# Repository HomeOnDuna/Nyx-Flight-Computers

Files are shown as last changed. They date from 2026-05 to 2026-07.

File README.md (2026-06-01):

# Nyx-Flight-Computer
Contains all details of the Nyx family of flight computers developed by Timothy Paige for UNSW rocketry

How to use:
 - Make a local clone of the entire repositry
 - Open the project you want from the file it is in
 - Enjoy!

To add parts to the library:
 - All parts go in the UNSW Rocketry parts folder (single parrts library)
 - Open a project and add the symbol into the UNSW Rocketry Library (symbol library, via import)
 - Put the footprint in the footprints.pretty folder of the parts folder
 - Put the 3D model in the 3D models folder
 - In the project, edit the symbol you have imported and assign the default footprint to the footprints.pretty folder footprint (.kicad_mod)
 - Edit the footprint you just added to add in the 3D model

How to reference filepaths:
**Do not use the default filepaths KiCAD generates. These will only work on your device!**
 - Remove the filepath up to Nyx-Flight-Computers (leave the \ after this)
 - Insert .. before this, which then re-references to a relative filepath (permitting multi-device use).

Current capabilites:
 - Literally nothing

Future capabilities targets:
 - Flight data recording from multiple sources to memory (SD cards)
 - Detection of phase of flight (not vehicle direction, speed etc., only are we 1) accelerating, and 2) going up or going down) and subsequent actions or data recording changes
 - Flight data high-speed capability to RAM during boost phase
 - Telemetry of currently relevant data
 - Pyro / chute deploy devices (linear actuator or other form)
 - Basic marking out of failed / erroring sensors in data recording

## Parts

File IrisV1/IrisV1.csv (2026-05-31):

Reference | Qty | Value | DNP | Exclude from BOM | Exclude from Board | Footprint | Datasheet
A3 | 1 | LPS22DFTR |  |  |  | Baro 1:XDCR_LPS22DFTR
C2,C3,C4,C10 | 4 | 10uF |  |  |  | Capacitor_SMD:C_0603_1608Metric
C8,C21,C22,C26,C27,C32,C34,C35,C36 | 9 | 100nF |  |  |  | Capacitor_SMD:C_0603_1608Metric
C12,C13,C14 | 3 | 22uF |  |  |  | Capacitor_SMD:C_0603_1608Metric
C15,C24 | 2 | 47uF |  |  |  | Capacitor_SMD:C_0603_1608Metric
C20 | 1 | 1uF |  |  |  | Capacitor_SMD:C_0603_1608Metric
D1,D2,D3,D4 | 4 | LED |  |  |  | LED_SMD:LED_0603_1608Metric
D5 | 1 | PRTR5V0U2X |  |  |  | Package_TO_SOT_SMD:SOT-143 | https://assets.nexperia.com/documents/data-sheet/PRTR5V0U2X.pdf
J1,J7 | 2 | Conn_02x02_Odd_Even |  |  |  | Connector_PinHeader_2.54mm:PinHeader_2x02_P2.54mm_Vertical
J3 | 1 | USB4110GFA |  |  |  | USB:GCT_USB4110GFA
J4 | 1 | Conn_01x04 |  |  |  | Connector_PinHeader_2.54mm:PinHeader_1x04_P2.54mm_Vertical
J5,J6 | 2 | MSD-10-C |  |  |  | microSd card locking:CUI_MSD-10-C
J13,J14,J16,J21,J22 | 5 | TB002-500-02BE |  |  |  | screw terminal:CUI_TB002-500-02BE
L1 | 1 | 1.5uH |  |  |  | inductor:1277AS-H-1R0M=P2_MUR-M
LS1 | 1 | CMI-1295-03TH |  |  |  | low volt buzzer:SPKR_CMI-1295-03TH
Q1 | 1 | SI4909DY-T1-GE3 |  |  |  | pyro 1:SOIC_09DY-T1-GE3_VIS | https://www.vishay.com/doc?67077
Q2 | 1 | MBT3904DW1T1G |  |  |  | npn 1:SOT-363&slash_SC-88&slash_SC70-6&slash_CASE419B_OSI | MBT3904DW1T1G
R1,R2,R16,R24,R27,R28 | 6 | 1k |  |  |  | Resistor_SMD:R_0603_1608Metric
R3,R4,R5,R6 | 4 | 1.3k |  |  |  | Resistor_SMD:R_0603_1608Metric
R7,R8,R10,R13,R19,R22,R25,R26,R31,R58 | 10 | 10k |  |  |  | Resistor_SMD:R_0603_1608Metric
R9 | 1 | 100k |  |  |  | Resistor_SMD:R_0603_1608Metric
R11 | 1 | 470k |  |  |  | Resistor_SMD:R_0603_1608Metric
R12 | 1 | 150k |  |  |  | Resistor_SMD:R_0603_1608Metric
R15,R23 | 2 | 9k |  |  |  | Resistor_SMD:R_0603_1608Metric
R17,R18 | 2 | 5.1k |  |  |  | Resistor_SMD:R_0603_1608Metric
R29,R32 | 2 | 39k |  |  |  | Resistor_SMD:R_0603_1608Metric
R30,R57 | 2 | 56k |  |  |  | Resistor_SMD:R_0603_1608Metric
R45,R46 | 2 | 3.3k |  |  |  | Resistor_SMD:R_0603_1608Metric
TP1,TP2,TP3,TP4,TP5,TP6,TP7,TP8,TP9,TP10 | 10 | TestPoint |  |  |  | TestPoint:TestPoint_Pad_D1.5mm
U1 | 1 | LSM6DSV80XTR |  |  |  | Acc 1:QFN_LSM6DSV80XTR_STM | https://www.st.com/resource/en/datasheet/lsm6dsv80x.pdf
U2 | 1 | ESDS302DBVR |  |  |  | esd:DBV0005A_L | https://www.ti.com/lit/gpn/esds302
U3 | 1 | ESP32-S3-WROOM-1U-N4 |  |  |  | ESP32-S3:XCVR_ESP32-S3-WROOM-1U-N4
U18 | 1 | MS561101BA03-50 |  |  |  | ms5611:SON8_MS5611_TEC | https://www.te.com/commerce/DocumentDelivery/DDEController?Action=srchrtrv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
U20 | 1 | BMI323 |  |  |  | BMI323:BMI323_BOS | BMI323
U22 | 1 | TPS63070RNMR |  |  |  | TPS63070:RNM0015A | https://www.ti.com/lit/gpn/tps63070

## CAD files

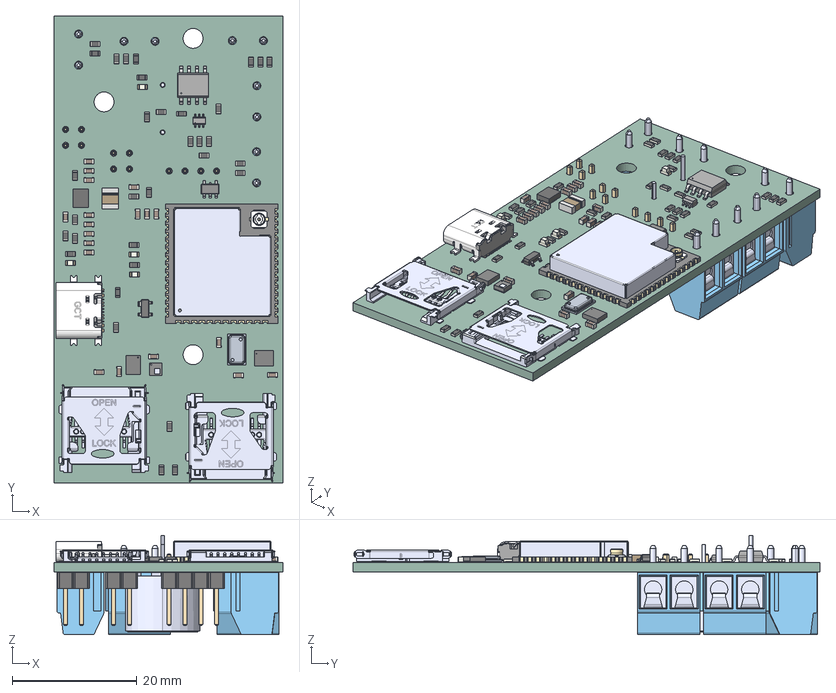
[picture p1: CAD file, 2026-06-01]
IrisV1/.step
36.7 x 75.0 x 16.0 mm
C_0603_1608Metric x 19
R_0603_1608Metric x 33
c-ms561101ba03-50-1-3d
SOT-363SC-88SC70-6CASE419B_OSI
SOT-143
LPS22DFTR
USB4110-GF-A_revB(1) MF
LED_0603_1608Metric x 4
MSD-10-C x 2
BMI323_BOS
ESP32-S3-WROOM-1U-N4
BODY-SOT
LEAD-SOT x 5
LEAD-DUMMY
QFN_LSM6DSV80XTR_STM
FRAME-RNM0015A
BODY-QFN
PIN1-ID
1277AS-H-1R0MP2_MUR
SOIC_09DY-T1-GE3_VIS
CMI-1295-03TH
PinHeader_2x02_P2.54mm_Vertical x 2
TB002-500-02P_Blue - S x 5
PinHeader_1x04_P2.54mm_Vertical
IrisV1_PCB

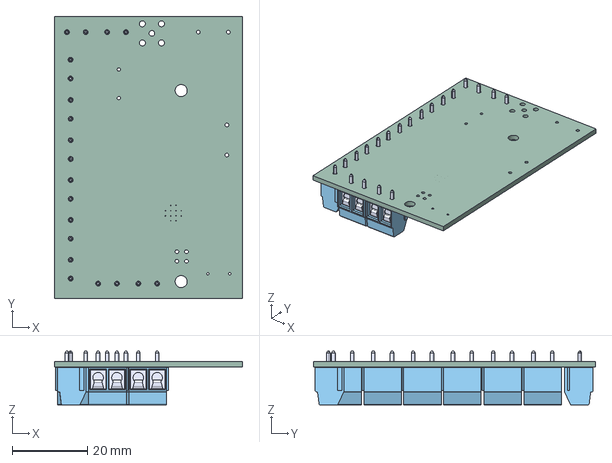
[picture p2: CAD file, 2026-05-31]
OneiroiV1/.step
50.0 x 75.0 x 14.4 mm
TB002-500-02P_Blue - S x 10
OneroiV1_PCB

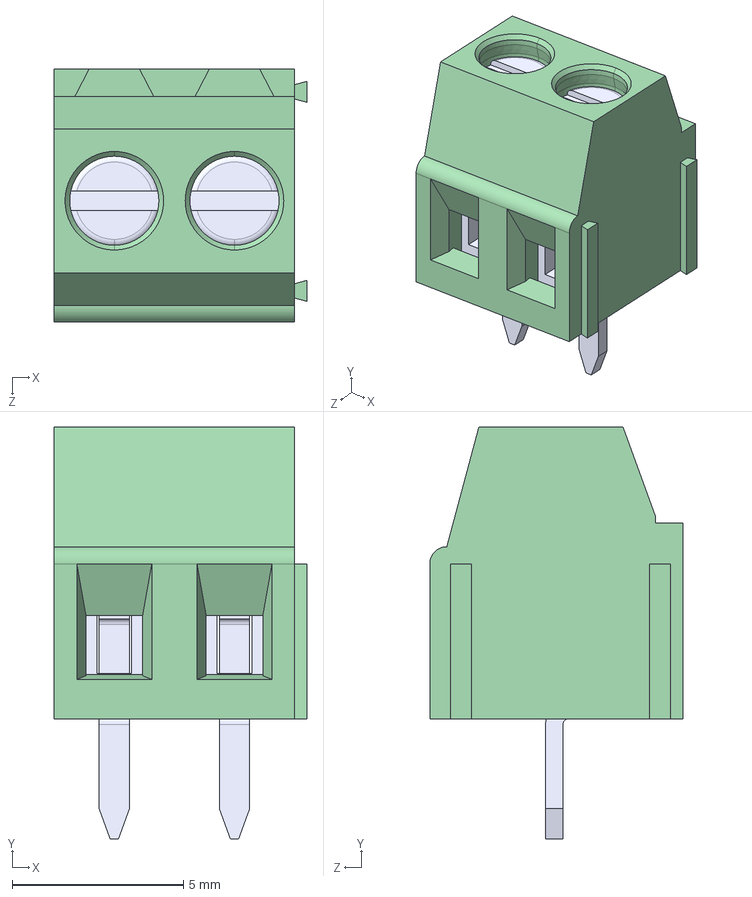
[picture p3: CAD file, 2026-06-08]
UNSW Rocketry Parts/3D models/EBWA-02-A.step
7.37 x 12.0 x 7.39 mm

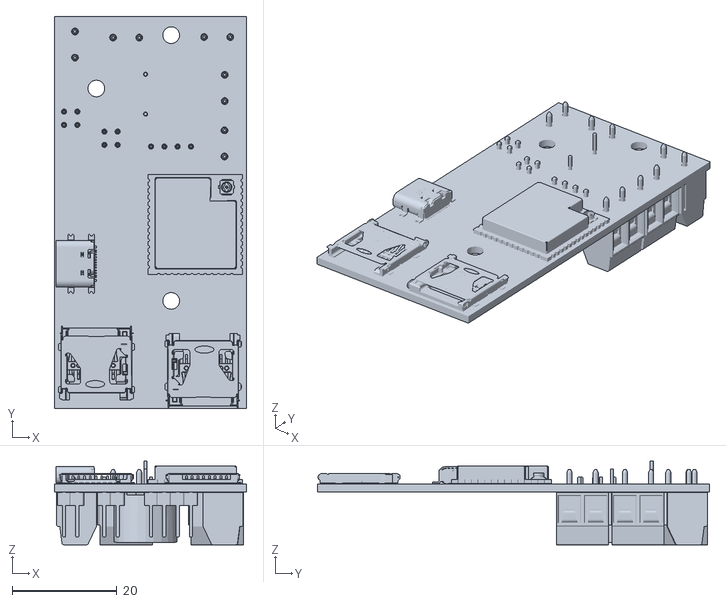
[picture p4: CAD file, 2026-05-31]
IrisV1/.stl
36.7 x 75.0 x 16.0

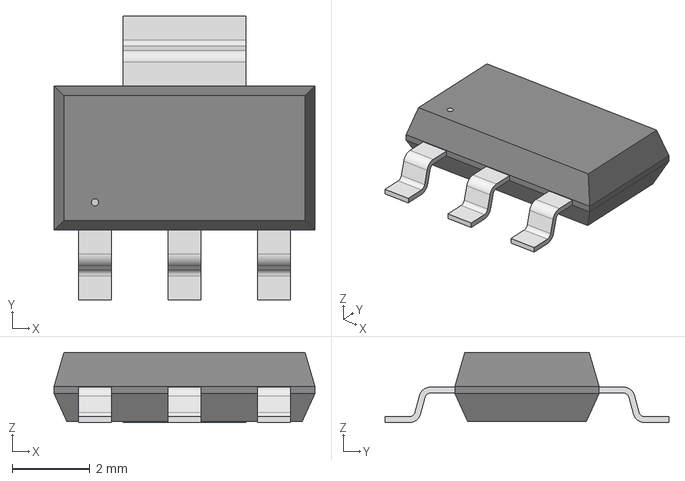
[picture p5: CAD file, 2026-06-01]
UNSW Rocketry Parts/3D models/SOT223_STM.step
6.71 x 7.29 x 1.81 mm

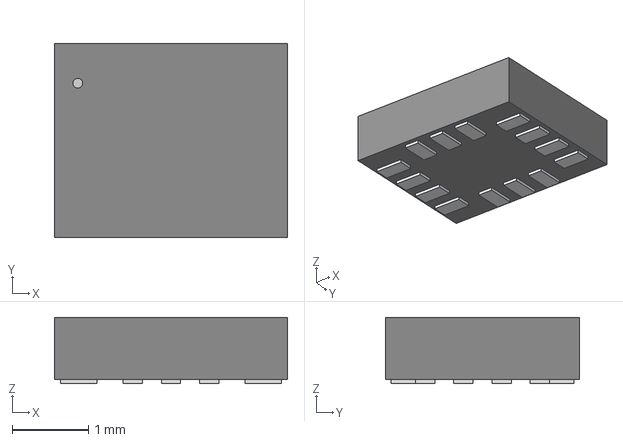
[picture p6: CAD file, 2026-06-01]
UNSW Rocketry Parts/3D models/BMI270_BOS.step
3.05 x 2.54 x 0.866 mm

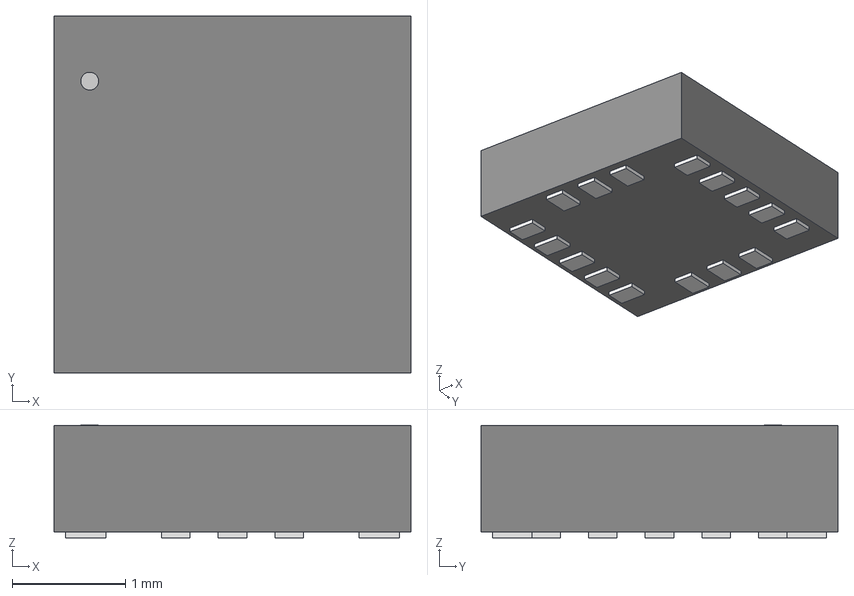
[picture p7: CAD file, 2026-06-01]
UNSW Rocketry Parts/3D models/QFN_31DLTR_STM.step
3.15 x 3.15 x 0.993 mm

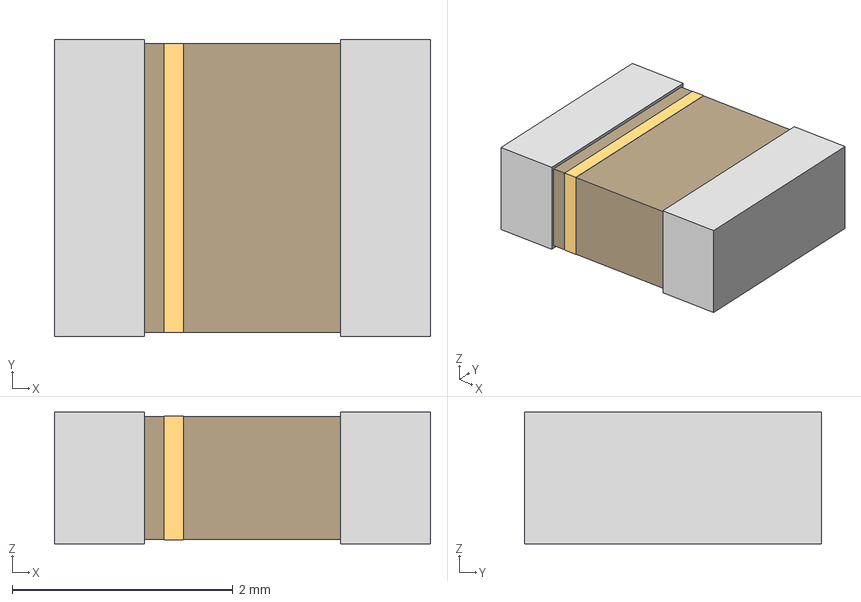
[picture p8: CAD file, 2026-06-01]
UNSW Rocketry Parts/3D models/1277AS-H-1R0MP2_MUR.step
3.40 x 2.69 x 1.19 mm

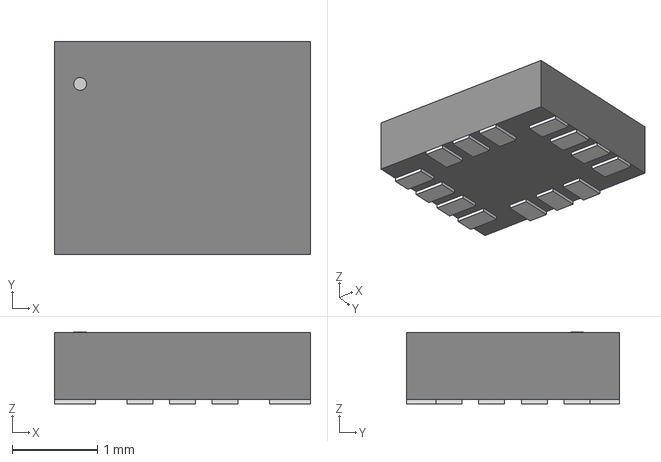
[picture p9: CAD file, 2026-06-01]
UNSW Rocketry Parts/3D models/QFN_LSM6DSV80XTR_STM.step
3.00 x 2.49 x 0.841 mm

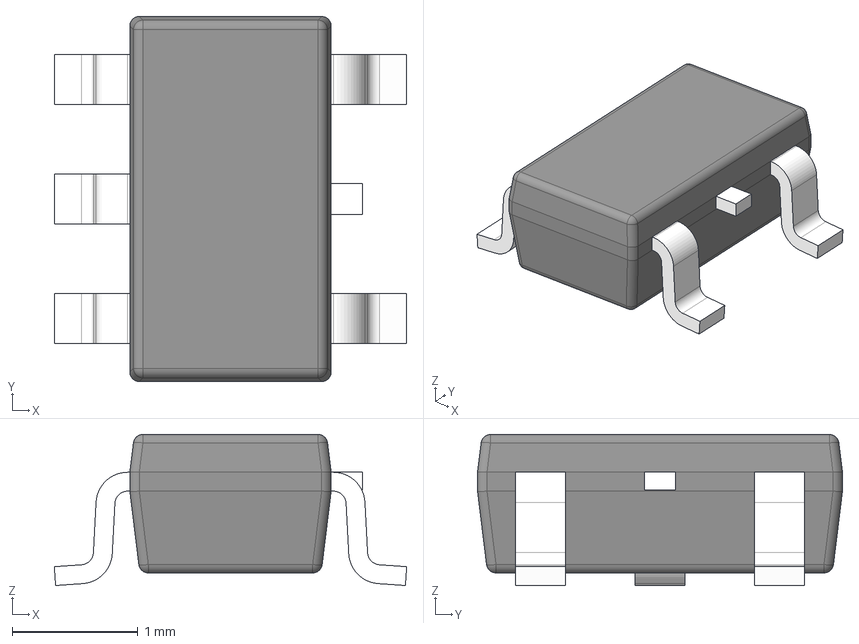
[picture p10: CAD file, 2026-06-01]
UNSW Rocketry Parts/3D models/DBV0005A.stp
2.80 x 2.90 x 1.20 mm
BODY-SOT
LEAD-SOT x 5
LEAD-DUMMY

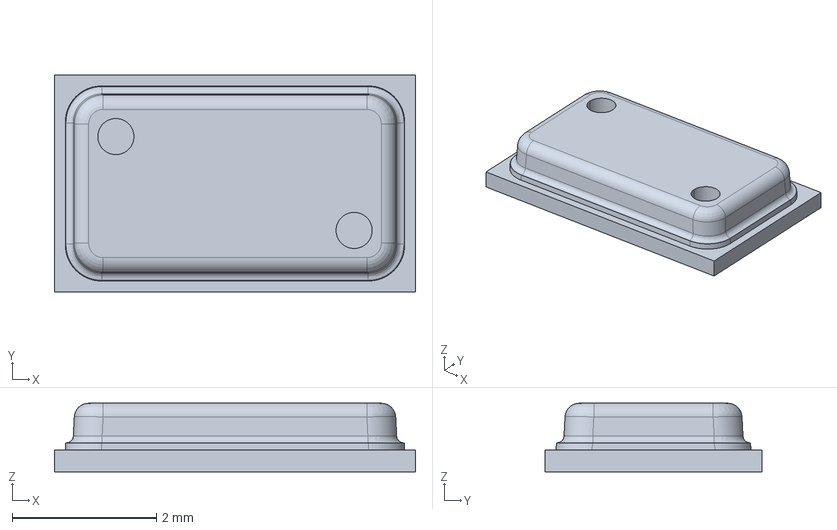
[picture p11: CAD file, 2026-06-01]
UNSW Rocketry Parts/3D models/c-ms561101ba03-50-1-3d.stp
5.00 x 3.00 x 0.95 mm

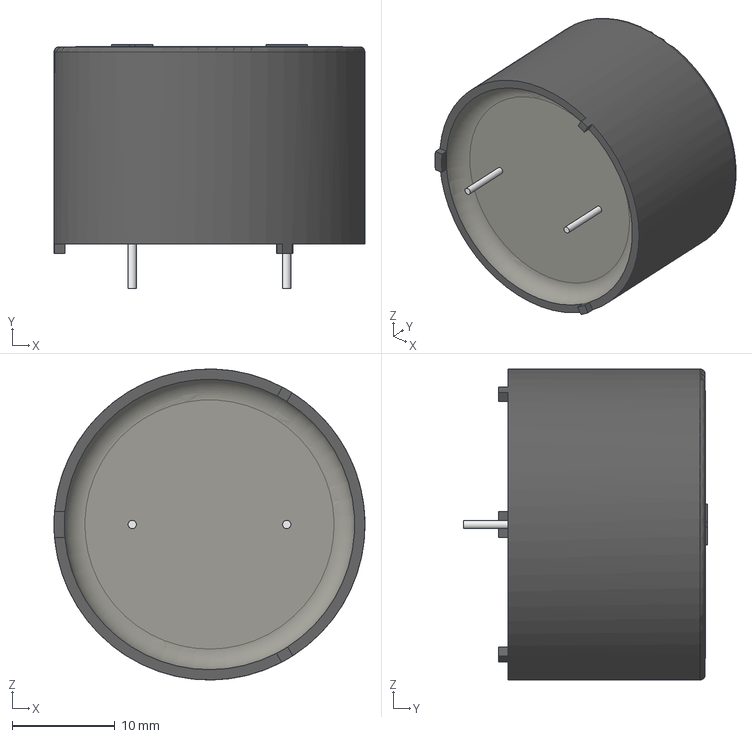
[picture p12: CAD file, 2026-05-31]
UNSW Rocketry Parts/3D models/AI-3035-TT-12V-R.step
30.2 x 23.6 x 30.2 mm

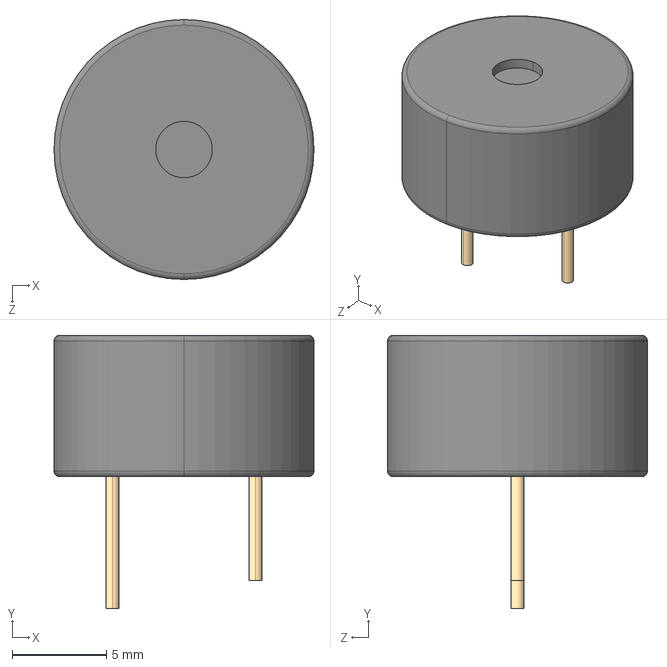
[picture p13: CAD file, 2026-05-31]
UNSW Rocketry Parts/3D models/CPI-1375-80T.step
13.8 x 14.5 x 13.8 mm

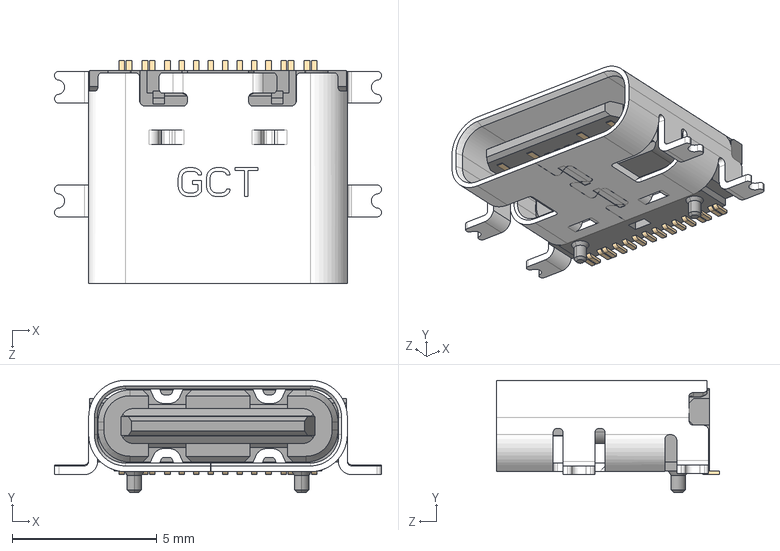
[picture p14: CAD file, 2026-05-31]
UNSW Rocketry Parts/3D models/USB4110GFA.step
11.3 x 3.89 x 7.70 mm

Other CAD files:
UNSW Rocketry Parts/3D models/TB002-500-02BE.step
UNSW Rocketry Parts/3D models/DRL0008A.stp
UNSW Rocketry Parts/3D models/IC_DMP3028LSD-13_DIO.step
UNSW Rocketry Parts/3D models/MSD-10-C.step
UNSW Rocketry Parts/3D models/3-1478978-1.step
UNSW Rocketry Parts/3D models/BMI323_BOS.step
UNSW Rocketry Parts/3D models/CMI-1295-03TH.step
UNSW Rocketry Parts/3D models/CONSMA001-SMD-G-T.step
UNSW Rocketry Parts/3D models/ESP32-S3-WROOM-1U-N4.step
UNSW Rocketry Parts/3D models/LPS22DFTR.step
UNSW Rocketry Parts/3D models/MAX-M10S-00B.step
UNSW Rocketry Parts/3D models/MSD-4-A.step
UNSW Rocketry Parts/3D models/RNM0015A.stp
UNSW Rocketry Parts/3D models/RUX0012A.stp
UNSW Rocketry Parts/3D models/SOIC_09DY-T1-GE3_VIS.step
UNSW Rocketry Parts/3D models/SOT-363SC-88SC70-6CASE419B_OSI.step
UNSW Rocketry Parts/3D models/SOT-363_DIO.step
UNSW Rocketry Parts/3D models/UFV_z90.stp

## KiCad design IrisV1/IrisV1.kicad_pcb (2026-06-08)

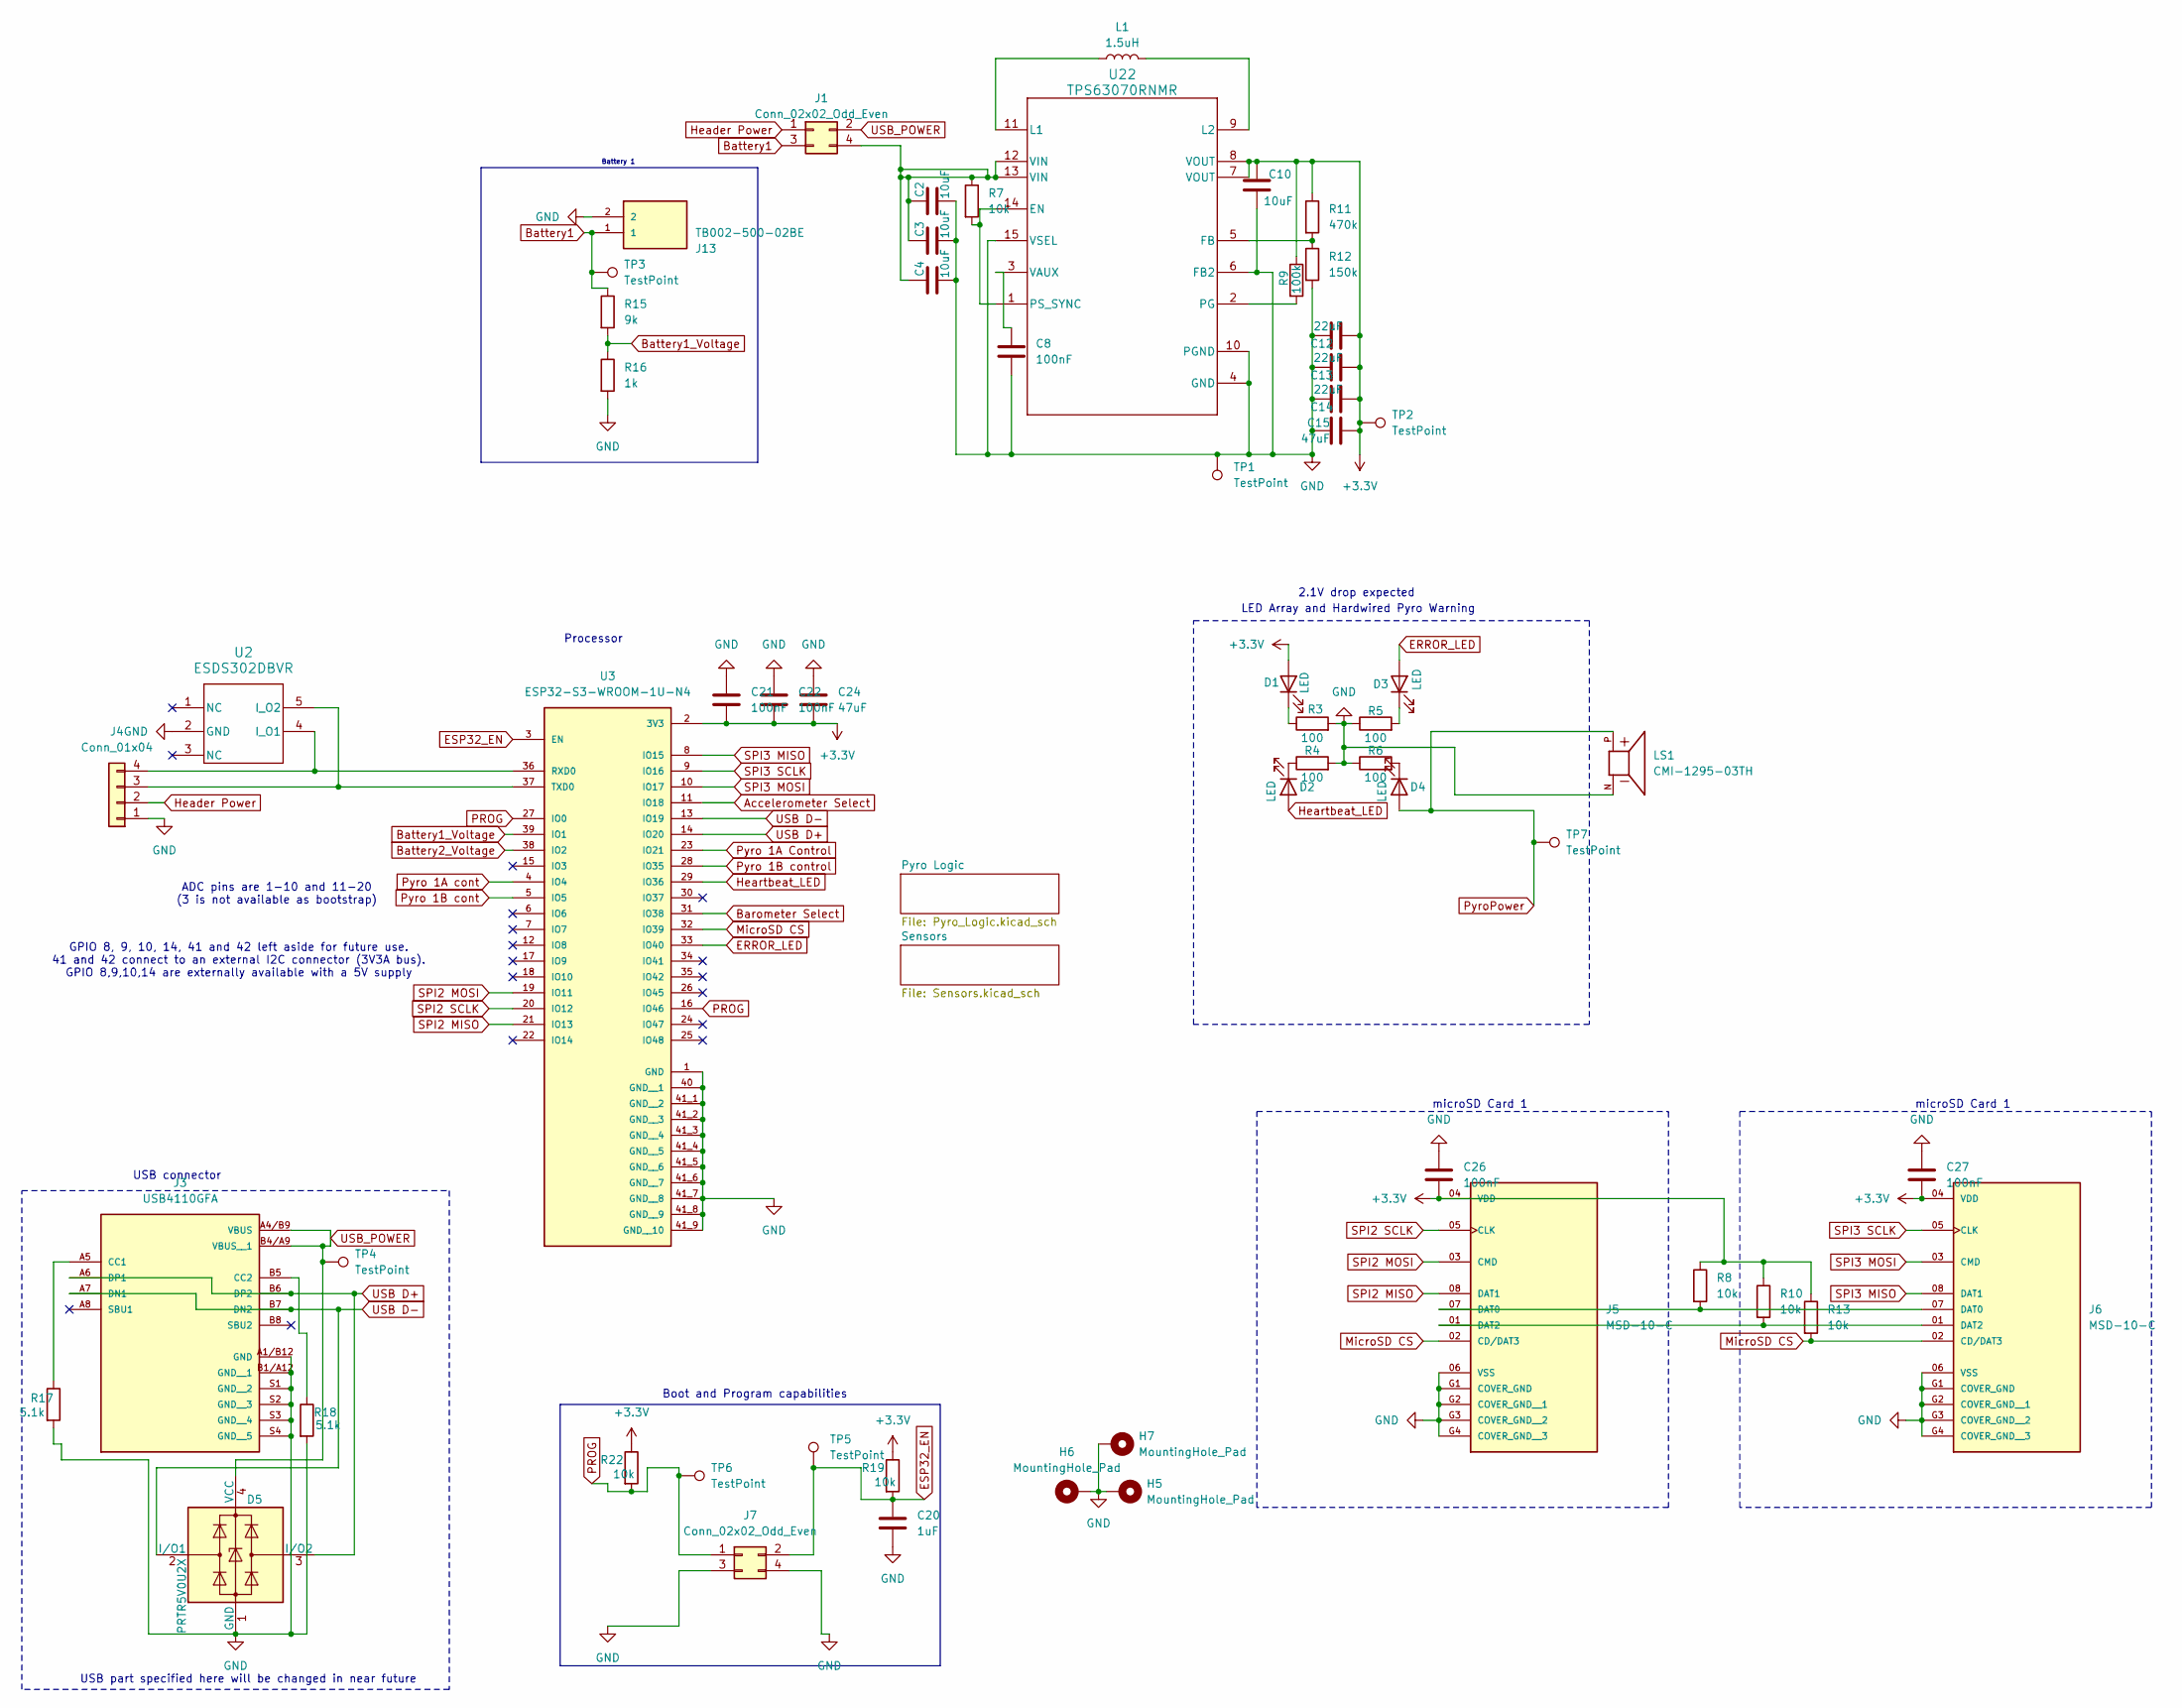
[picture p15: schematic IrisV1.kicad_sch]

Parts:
C2, C3, C4, C10: 10uF; C_0603_1608Metric
C8, C21, C22, C26, C27: 100nF; C_0603_1608Metric
C12, C13, C14: 22uF; C_0603_1608Metric
C15, C24: 47uF; C_0603_1608Metric
C20: 1uF; C_0603_1608Metric
D1, D2, D3, D4: LED; LED_0603_1608Metric
D5: PRTR5V0U2X; SOT-143
H5, H6, H7: MountingHole_Pad; MountingHole_3.2mm_M3_ISO7380_Pad_TopBottom
J1, J7: Conn_02x02_Odd_Even; PinHeader_2x02_P2.54mm_Vertical
J3: USB4110GFA; GCT_USB4110GFA
J4: Conn_01x04; PinHeader_1x04_P2.54mm_Vertical
J5, J6: MSD-10-C; CUI_MSD-10-C; PARTREV 1.0
J13: TB002-500-02BE; ADAMTECH_EBWA-02-A; PARTREV A
L1: 1.5uH; 1277AS-H-1R0M=P2_MUR-M
LS1: CMI-1295-03TH; SPKR_CMI-1295-03TH; PARTREV 1.0
R3, R4, R5, R6: 100; R_0603_1608Metric
R7, R8, R10, R13, R19, R22: 10k; R_0603_1608Metric
R9: 100k; R_0603_1608Metric
R11: 470k; R_0603_1608Metric
R12: 150k; R_0603_1608Metric
R15: 9k; R_0603_1608Metric
R16: 1k; R_0603_1608Metric
R17, R18: 5.1k; R_0603_1608Metric
TP1, TP2, TP3, TP4, TP5, TP6, TP7: TestPoint; TestPoint_Pad_D1.5mm
U2: ESDS302DBVR; DBV0005A_N
U3: ESP32-S3-WROOM-1U-N4; XCVR_ESP32-S3-WROOM-1U-N4; PARTREV v1.1
U22: TPS63070RNMR; RNM0015A

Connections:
+3.3V: C10.1, C12.2, C13.2, C14.2, C15.2, C21.2, C22.2, C24.2, C26.2, C27.2, D1.2 (A), J5.04 (VDD), J6.04 (VDD), R8.1, R9.1, R10.1, R11.1, R13.1, R19.1, R22.1, TP2.1 (1_1), U3.2 (3V3), U22.7 (VOUT), U22.8 (VOUT); also elsewhere on the board
Accelerometer Select: U3.11 (IO18); also elsewhere on the board
Barometer Select: U3.31 (IO38); also elsewhere on the board
Battery1: J1.3, J13.1, R15.1, TP3.1 (1_1)
Battery1_Voltage: R15.2, R16.1, U3.39 (IO1)
Battery2_Voltage: U3.38 (IO2); also elsewhere on the board
ERROR_LED: D3.2 (A), U3.33 (IO40)
ESP32_EN: C20.1, J7.2, R19.2, TP5.1 (1_1), U3.3 (EN)
GND: C2.1, C3.1, C4.1, C8.2, C10.2, C12.1, C13.1, C14.1, C15.1, C20.2, C21.1, C22.1, C24.1, C26.1, C27.1, D5.1 (GND), H5.1 (1_1), H6.1 (1_1), H7.1 (1_1), J3.A1/B12 (GND), J3.B1/A12 (GND__1), J3.S1 (GND__2), J3.S2 (GND__3), J3.S3 (GND__4), J3.S4 (GND__5), J4.1, J5.06 (VSS), J5.G1 (COVER_GND), J5.G2 (COVER_GND__1), J5.G3 (COVER_GND__2), J5.G4 (COVER_GND__3), J6.06 (VSS), J6.G1 (COVER_GND), J6.G2 (COVER_GND__1), J6.G3 (COVER_GND__2), J6.G4 (COVER_GND__3), J7.3, J7.4, J13.2, LS1.N, R3.2, R4.2, R5.1, R6.1, R12.2, R16.2, R17.2, R18.2, TP1.1 (1_1), U2.2 (GND), U3.1 (GND), U3.40 (GND__1), U3.41_1 (GND__2), U3.41_2 (GND__3), U3.41_3 (GND__4), U3.41_4 (GND__5), U3.41_5 (GND__6), U3.41_6 (GND__7), U3.41_7 (GND__8), U3.41_8 (GND__9), U3.41_9 (GND__10), U22.4 (GND), U22.6 (FB2), U22.10 (PGND), U22.15 (VSEL); also elsewhere on the board
Header Power: J1.1, J4.2
Heartbeat_LED: D2.2 (A), U3.29 (IO36)
MicroSD CS: J5.02 (CD/DAT3), J6.02 (CD/DAT3), R13.2, U3.32 (IO39)
unnamed: D1.1 (K), R3.1
unnamed: D2.1 (K), R4.1
unnamed: D3.1 (K), R5.2
unnamed: D4.1 (K), R6.2
unnamed: C2.2, C3.2, C4.2, J1.4, R7.1, U22.12 (VIN), U22.13 (VIN)
unnamed: J3.A5 (CC1), R17.1
unnamed: J3.B5 (CC2), R18.1
unnamed: J4.3, U2.5 (I_O2), U3.37 (TXD0)
unnamed: J4.4, U2.4 (I_O1), U3.36 (RXD0)
unnamed: J5.07 (DAT0), J6.07 (DAT0), R8.2
unnamed: J5.01 (DAT2), J6.01 (DAT2), R10.2
unnamed: R7.2, U22.1 (PS_SYNC), U22.14 (EN)
unnamed: R11.2, R12.1, U22.5 (FB)
unnamed: L1.1, U22.11 (L1)
unnamed: L1.2, U22.9 (L2)
unnamed: R9.2, U22.2 (PG)
unnamed: C8.1, U22.3 (VAUX)
PROG: J7.1, R22.2, TP6.1 (1_1), U3.16 (IO46), U3.27 (IO0)
Pyro 1A Control: U3.23 (IO21); also elsewhere on the board
Pyro 1A cont: U3.4 (IO4); also elsewhere on the board
Pyro 1B cont: U3.5 (IO5); also elsewhere on the board
Pyro 1B control: U3.28 (IO35); also elsewhere on the board
PyroPower: D4.2 (A), LS1.P, TP7.1 (1_1); also elsewhere on the board
SPI2 MISO: J5.08 (DAT1), U3.21 (IO13); also elsewhere on the board
SPI2 MOSI: J5.03 (CMD), U3.19 (IO11); also elsewhere on the board
SPI2 SCLK: J5.05 (CLK), U3.20 (IO12); also elsewhere on the board
SPI3 MISO: J6.08 (DAT1), U3.8 (IO15); also elsewhere on the board
SPI3 MOSI: J6.03 (CMD), U3.10 (IO17); also elsewhere on the board
SPI3 SCLK: J6.05 (CLK), U3.9 (IO16); also elsewhere on the board
USB D+: D5.3 (I/O2), J3.A6 (DP1), J3.B6 (DP2), U3.14 (IO20)
USB D-: D5.2 (I/O1), J3.A7 (DN1), J3.B7 (DN2), U3.13 (IO19)
USB_POWER: D5.4 (VCC), J1.2, J3.A4/B9 (VBUS), J3.B4/A9 (VBUS__1), TP4.1 (1_1)

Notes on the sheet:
ADC pins are 1-10 and 11-20 (3 is not available as bootstrap)
2.1V drop expected
Boot and Program capabilities
GPIO 8, 9, 10, 14, 41 and 42 left aside for future use. 41 and 42 connect to an external I2C connector (3V3A bus). GPIO 8,9,10,14 are externally available with a 5V supply
Battery 1
USB part specified here will be changed in near future
Processor
LED Array and Hardwired Pyro Warning
microSD Card 1
USB connector

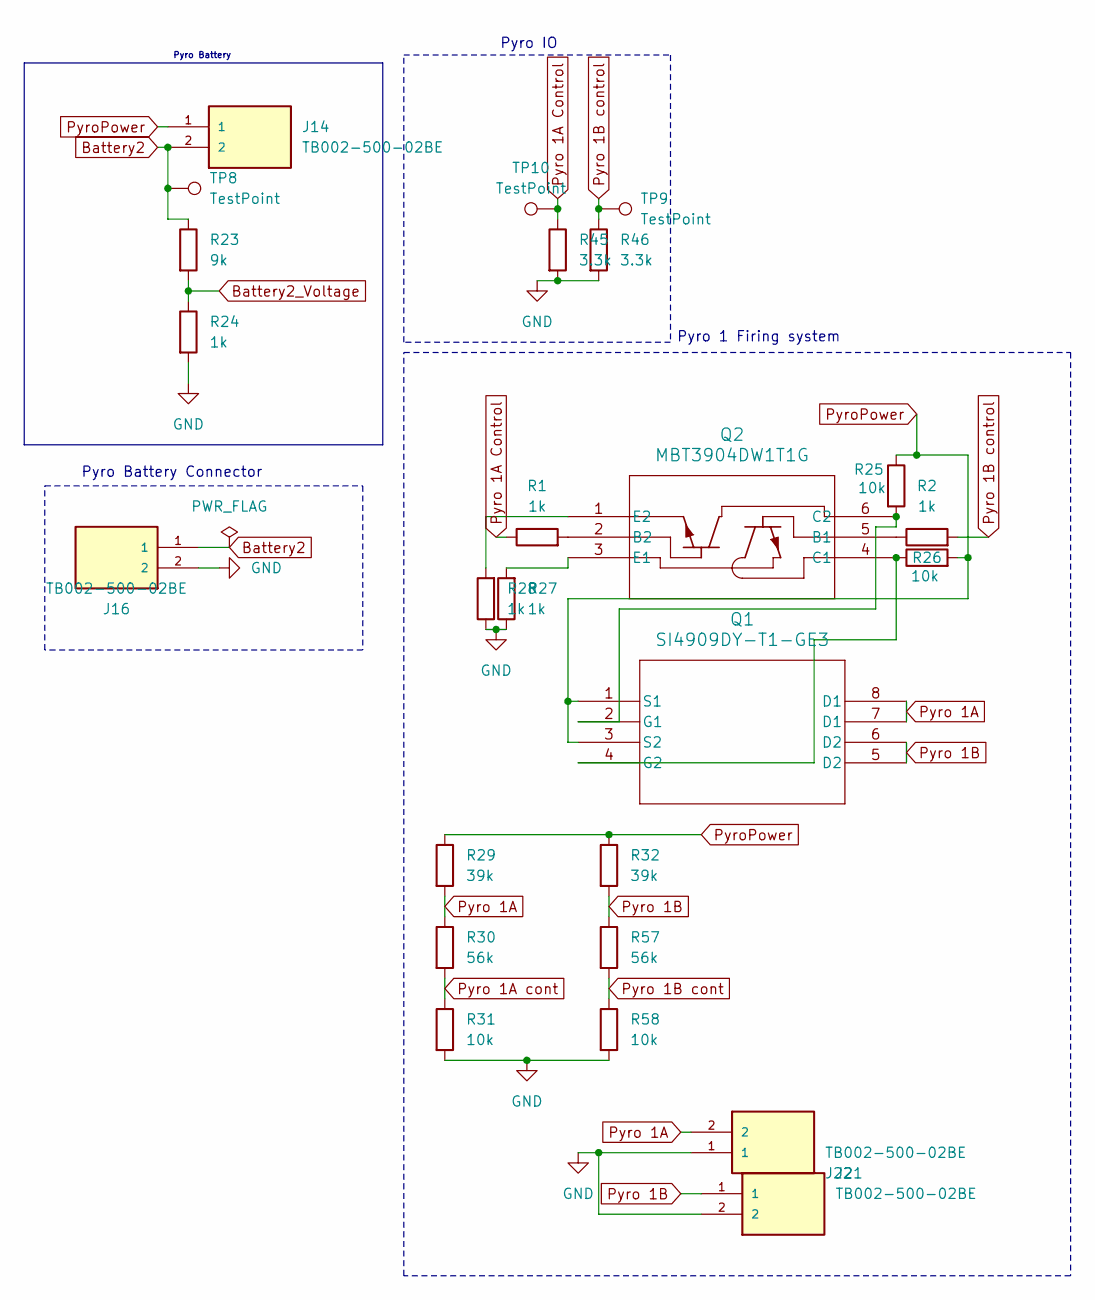
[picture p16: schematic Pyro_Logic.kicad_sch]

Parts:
J14, J16, J21, J22: TB002-500-02BE; ADAMTECH_EBWA-02-A; PARTREV A
Q1: SI4909DY-T1-GE3; SOIC_09DY-T1-GE3_VIS
Q2: MBT3904DW1T1G; SOT-363&slash_SC-88&slash_SC70-6&slash_CASE419B_OSI
R1, R2, R24, R27, R28: 1k; R_0603_1608Metric
R23: 9k; R_0603_1608Metric
R25, R26, R31, R58: 10k; R_0603_1608Metric
R29, R32: 39k; R_0603_1608Metric
R30, R57: 56k; R_0603_1608Metric
R45, R46: 3.3k; R_0603_1608Metric
TP8, TP9, TP10: TestPoint; TestPoint_Pad_D1.5mm

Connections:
Battery2: J14.2, J16.1, R23.1, TP8.1 (1_1)
Battery2_Voltage: R23.2, R24.1; also elsewhere on the board
GND: J16.2, J21.2, J22.1, R24.2, R27.1, R28.1, R31.2, R45.2, R46.2, R58.2; also elsewhere on the board
unnamed: Q1.2 (G1), Q2.6 (C2), R25.2
unnamed: Q1.4 (G2), Q2.4 (C1), R26.1
unnamed: Q2.5 (B1), R2.1
unnamed: Q2.2 (B2), R1.2
unnamed: Q2.3 (E1), R27.2
unnamed: Q2.1 (E2), R28.2
Pyro 1A: J22.2, Q1.7 (D1), Q1.8 (D1), R29.2, R30.1
Pyro 1A Control: R1.1, R45.1, TP10.1 (1_1); also elsewhere on the board
Pyro 1A cont: R30.2, R31.1; also elsewhere on the board
Pyro 1B: J21.1, Q1.5 (D2), Q1.6 (D2), R32.2, R57.1
Pyro 1B cont: R57.2, R58.1; also elsewhere on the board
Pyro 1B control: R2.2, R46.1, TP9.1 (1_1); also elsewhere on the board
PyroPower: J14.1, Q1.1 (S1), Q1.3 (S2), R25.1, R26.2, R29.1, R32.1; also elsewhere on the board

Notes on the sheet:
Pyro Battery Connector
Pyro IO
Pyro Battery
Pyro 1 Firing system

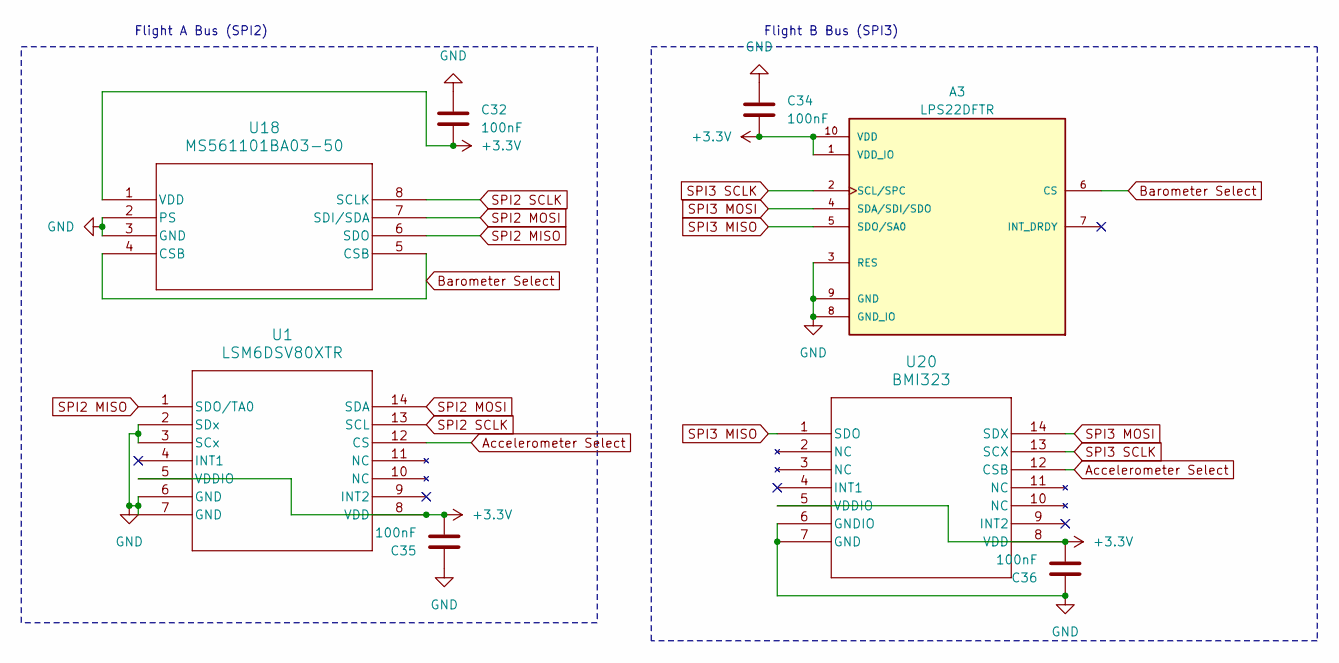
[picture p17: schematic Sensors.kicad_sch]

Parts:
A3: LPS22DFTR; XDCR_LPS22DFTR; PARTREV 3
C32, C34, C35, C36: 100nF; C_0603_1608Metric
U1: LSM6DSV80XTR; QFN_LSM6DSV80XTR_STM
U18: MS561101BA03-50; SON8_MS5611_TEC
U20: BMI323; BMI323_BOS

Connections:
+3.3V: A3.1 (VDD_IO), A3.10 (VDD), C32.2, C34.2, C35.2, C36.2, U1.5 (VDDIO), U1.8 (VDD), U18.1 (VDD), U20.5 (VDDIO), U20.8 (VDD); also elsewhere on the board
Accelerometer Select: U1.12 (CS), U20.12 (CSB); also elsewhere on the board
Barometer Select: A3.6 (CS), U18.4 (CSB), U18.5 (CSB); also elsewhere on the board
GND: A3.3 (RES), A3.8 (GND_IO), A3.9 (GND), C32.1, C34.1, C35.1, C36.1, U1.2 (SDx), U1.3 (SCx), U1.6 (GND), U1.7 (GND), U18.2 (PS), U18.3 (GND), U20.6 (GNDIO), U20.7 (GND); also elsewhere on the board
SPI2 MISO: U1.1 (SDO/TA0), U18.6 (SDO); also elsewhere on the board
SPI2 MOSI: U1.14 (SDA), U18.7 (SDI/SDA); also elsewhere on the board
SPI2 SCLK: U1.13 (SCL), U18.8 (SCLK); also elsewhere on the board
SPI3 MISO: A3.5 (SDO/SA0), U20.1 (SDO); also elsewhere on the board
SPI3 MOSI: A3.4 (SDA/SDI/SDO), U20.14 (SDX); also elsewhere on the board
SPI3 SCLK: A3.2 (SCL/SPC), U20.13 (SCX); also elsewhere on the board

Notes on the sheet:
Flight B Bus (SPI3)
Flight A Bus (SPI2)

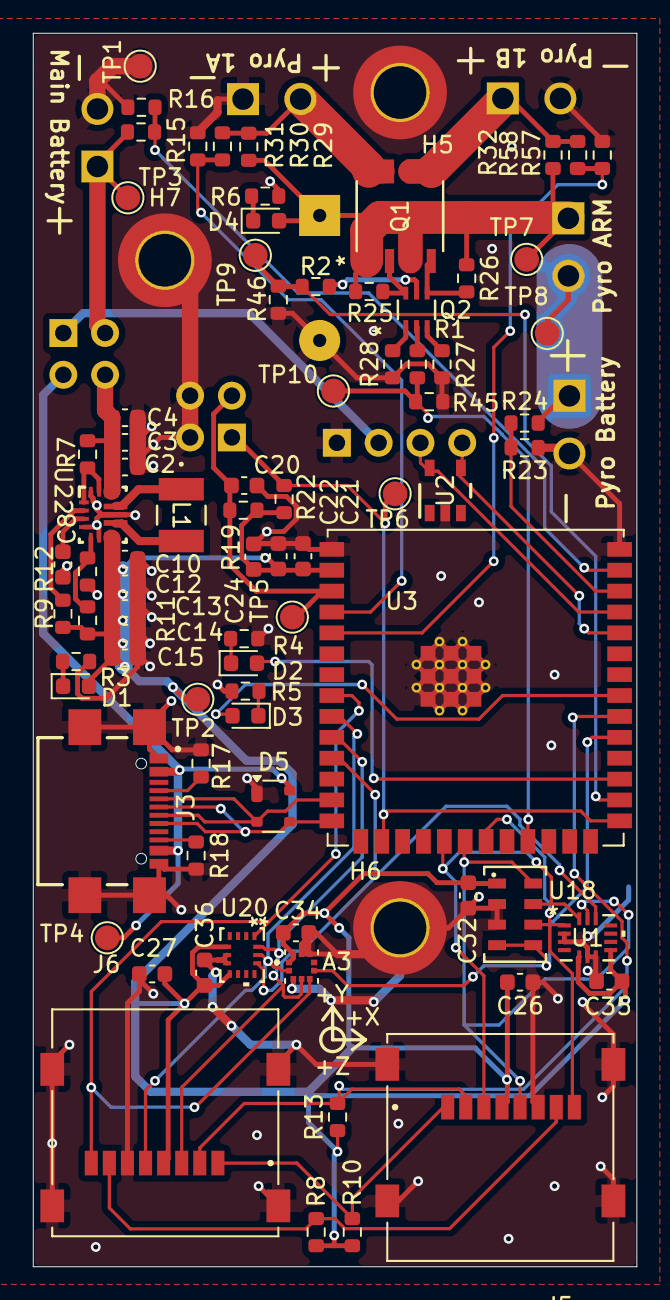
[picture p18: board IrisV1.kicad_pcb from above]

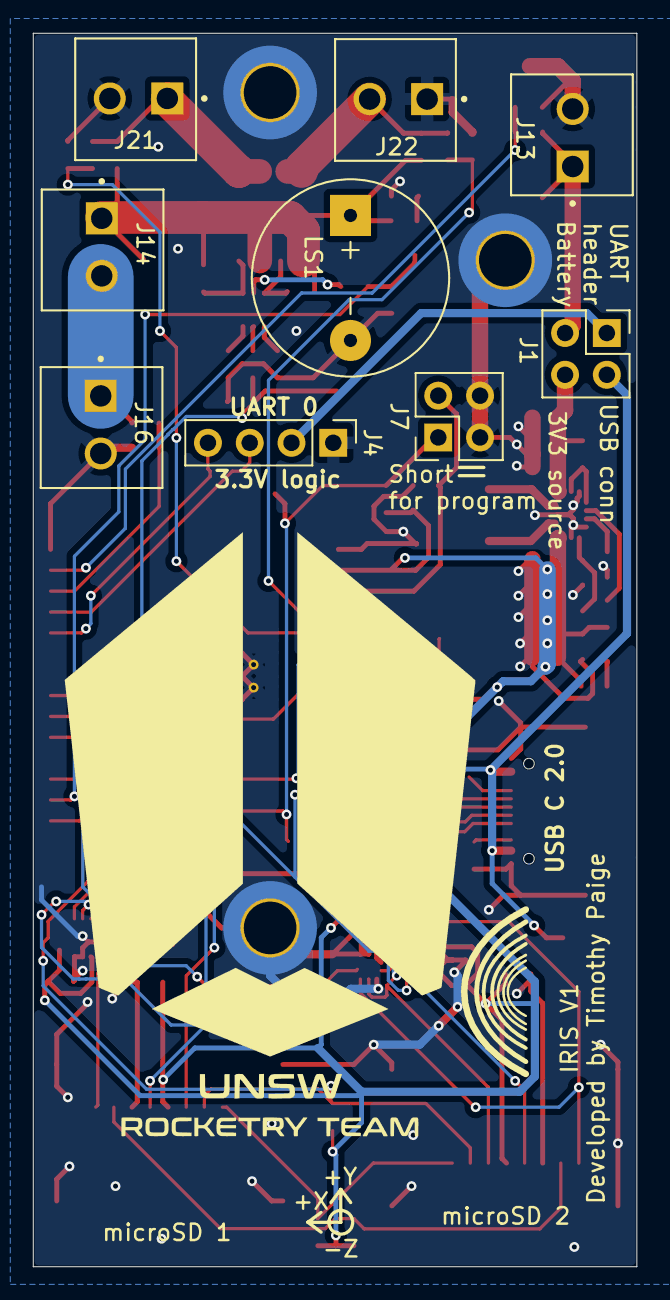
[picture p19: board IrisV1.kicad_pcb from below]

Board: 2 copper layers, 36.7 x 75.0 mm, 92 parts (9 on the bottom side), 53 nets.

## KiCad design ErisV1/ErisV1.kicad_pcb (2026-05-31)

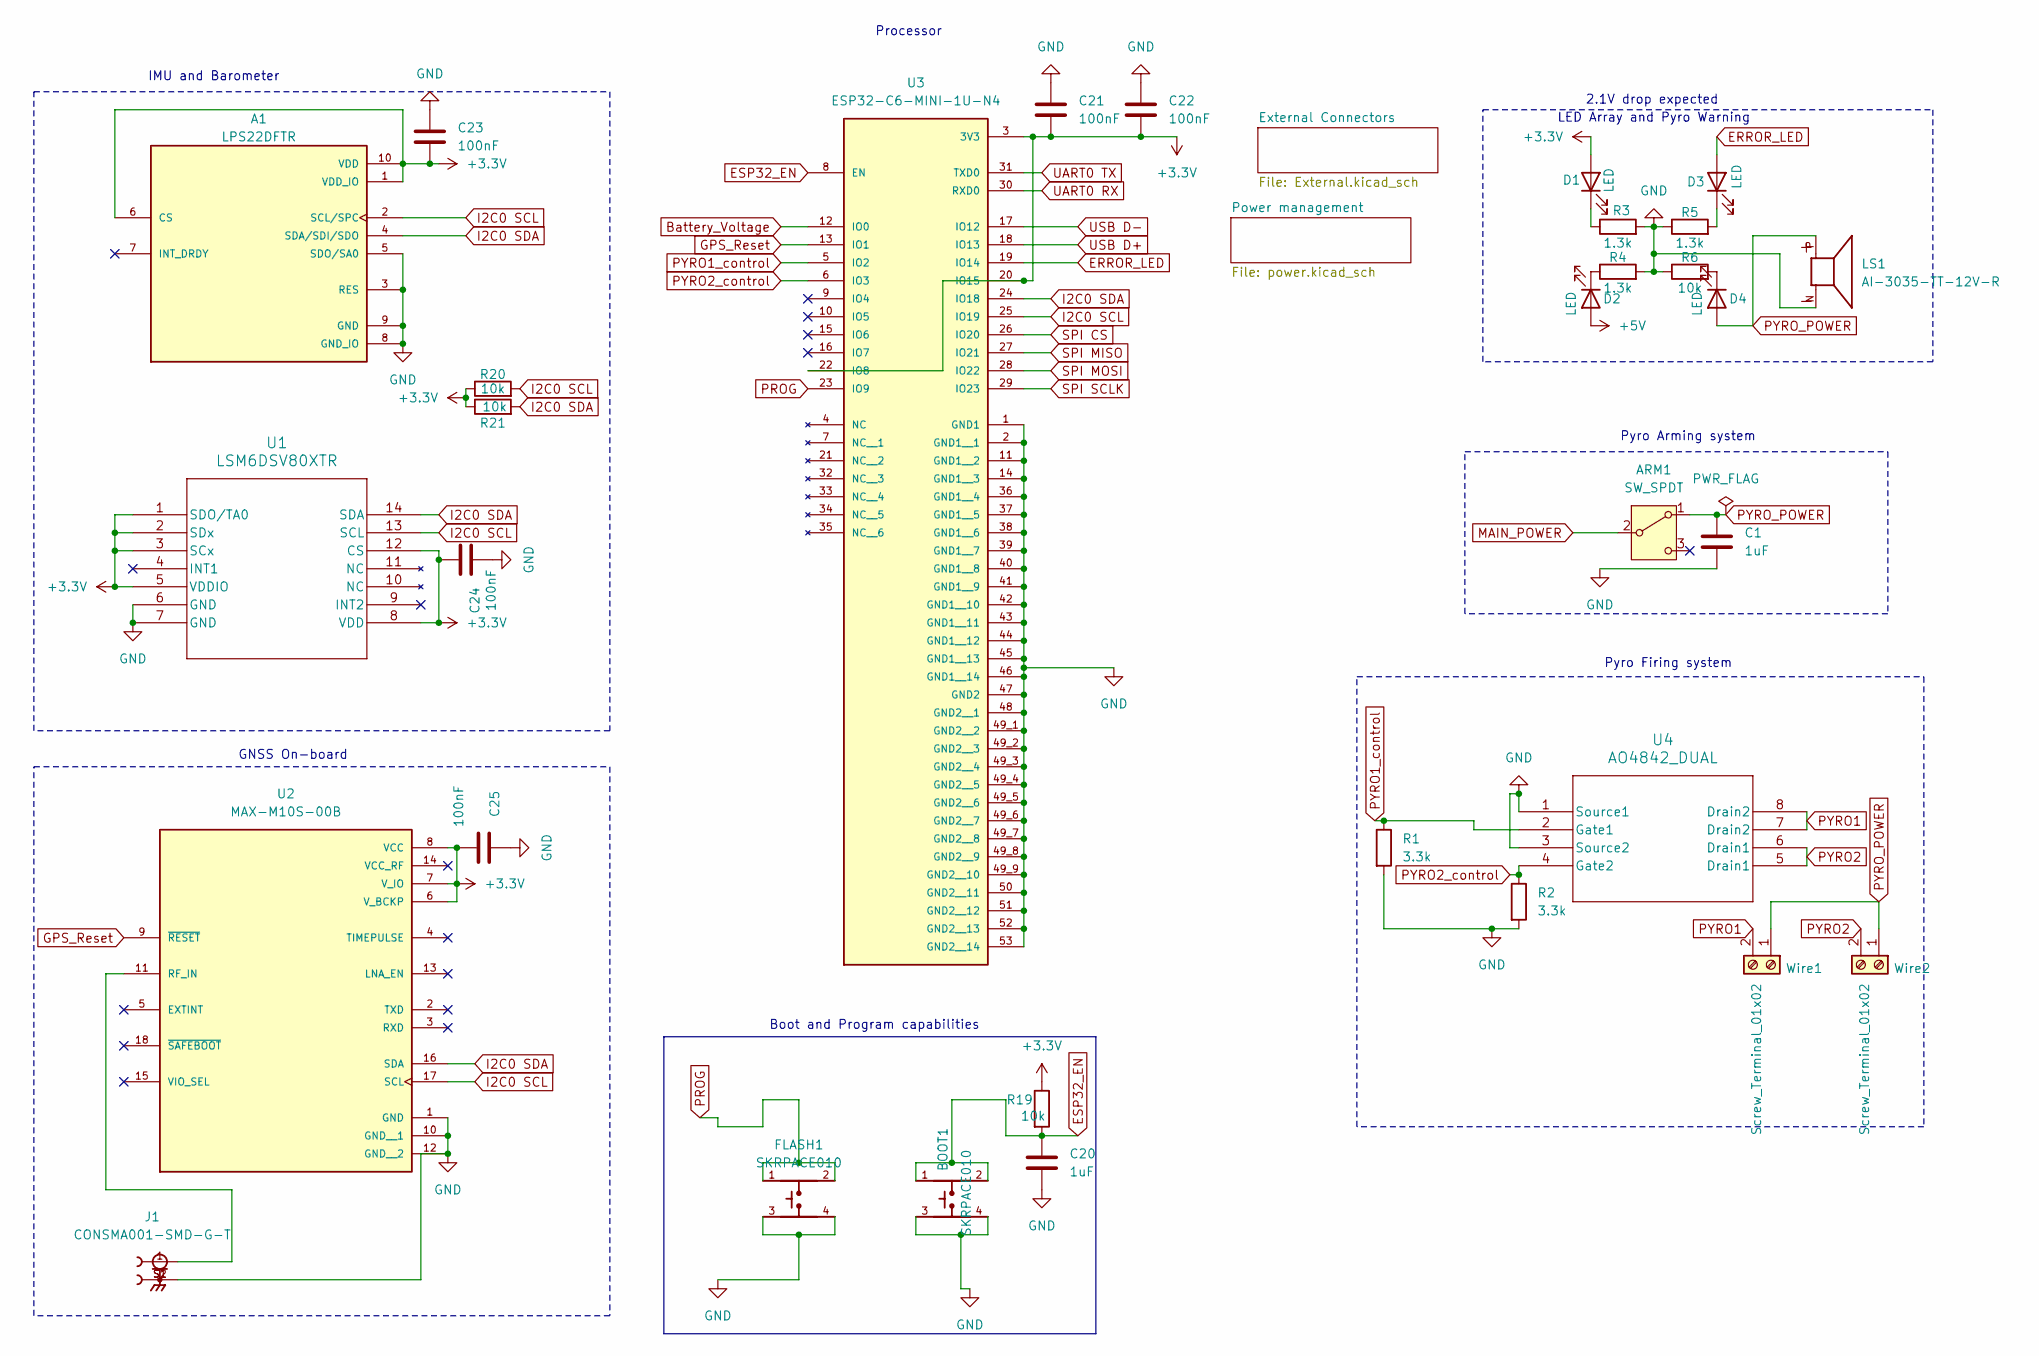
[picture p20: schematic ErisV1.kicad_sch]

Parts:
A1: LPS22DFTR; XDCR_LPS22DFTR; PARTREV 3
ARM1: SW_SPDT; PinSocket_1x02_P2.54mm_Vertical
BOOT1: SKRPACE010; SW_SKRPACE010
C1, C20: 1uF; C_0603_1608Metric
C21, C22, C23, C24, C25: 100nF; C_0603_1608Metric
D1, D2, D3, D4: LED; LED_0603_1608Metric
FLASH1: SKRPACE010; SW_SKRPACE010
J1: CONSMA001-SMD-G-T; LINX_CONSMA001-SMD-G-T
LS1: AI-3035-TT-12V-R; XDCR_AI-3035-TT-12V-R; PARTREV 12/13/2018
R1, R2: 3.3k; R_0603_1608Metric
R3, R4, R5: 1.3k; R_0603_1608Metric
R6, R19, R20, R21: 10k; R_0603_1608Metric
U1: LSM6DSV80XTR; QFN_LSM6DSV80XTR_STM
U2: MAX-M10S-00B; XCVR_MAX-M10S-00B; PARTREV C1
U3: ESP32-C6-MINI-1U-N4; XCVR_ESP32-C6-MINI-1U-N4; PARTREV 1.0
U4: AO4842_DUAL; SOIC-8_3.9x4.9mm_P1.27mm
Wire1, Wire2: Screw_Terminal_01x02; PinHeader_1x02_P2.54mm_Vertical

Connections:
+3.3V: A1.1 (VDD_IO), A1.6 (CS), A1.10 (VDD), C21.2, C22.2, C23.2, C24.2, C25.2, D1.2 (A), R19.1, R20.1, R21.1, U1.1 (SDO/TA0), U1.2 (SDx), U1.3 (SCx), U1.5 (VDDIO), U1.8 (VDD), U1.12 (CS), U2.6 (V_BCKP), U2.7 (V_IO), U2.8 (VCC), U3.3 (3V3), U3.20 (IO15), U3.22 (IO8); also elsewhere on the board
+5V: D2.2 (A); also elsewhere on the board
Battery_Voltage: U3.12 (IO0); also elsewhere on the board
ERROR_LED: D3.2 (A), U3.19 (IO14)
ESP32_EN: BOOT1.1, BOOT1.2, C20.1, R19.2, U3.8 (EN)
GND: A1.3 (RES), A1.5 (SDO/SA0), A1.8 (GND_IO), A1.9 (GND), BOOT1.3, BOOT1.4, C1.2, C20.2, C21.1, C22.1, C23.1, C24.1, C25.1, FLASH1.3, FLASH1.4, J1.S1, J1.S2, LS1.N, R1.2, R2.2, R3.2, R4.2, R5.1, R6.1, U1.6 (GND), U1.7 (GND), U2.1 (GND), U2.10 (GND__1), U2.12 (GND__2), U3.1 (GND1), U3.2 (GND1__1), U3.11 (GND1__2), U3.14 (GND1__3), U3.36 (GND1__4), U3.37 (GND1__5), U3.38 (GND1__6), U3.39 (GND1__7), U3.40 (GND1__8), U3.41 (GND1__9), U3.42 (GND1__10), U3.43 (GND1__11), U3.44 (GND1__12), U3.45 (GND1__13), U3.46 (GND1__14), U3.47 (GND2), U3.48 (GND2__1), U3.49_1 (GND2__2), U3.49_2 (GND2__3), U3.49_3 (GND2__4), U3.49_4 (GND2__5), U3.49_5 (GND2__6), U3.49_6 (GND2__7), U3.49_7 (GND2__8), U3.49_8 (GND2__9), U3.49_9 (GND2__10), U3.50 (GND2__11), U3.51 (GND2__12), U3.52 (GND2__13), U3.53 (GND2__14), U4.1 (Source1), U4.3 (Source2); also elsewhere on the board
GPS_Reset: U2.9 (~RESET), U3.13 (IO1)
I2C0 SCL: A1.2 (SCL/SPC), R20.2, U1.13 (SCL), U2.17 (SCL), U3.25 (IO19)
I2C0 SDA: A1.4 (SDA/SDI/SDO), R21.2, U1.14 (SDA), U2.16 (SDA), U3.24 (IO18)
MAIN_POWER: ARM1.2 (B); also elsewhere on the board
unnamed: D1.1 (K), R3.1
unnamed: D2.1 (K), R4.1
unnamed: D3.1 (K), R5.2
unnamed: D4.1 (K), R6.2
unnamed: J1.1, U2.11 (RF_IN)
PROG: FLASH1.1, FLASH1.2, U3.23 (IO9)
PYRO1: U4.7 (Drain2), U4.8 (Drain2), Wire1.2
PYRO1_control: R1.1, U3.5 (IO2), U4.2 (Gate1)
PYRO2: U4.5 (Drain1), U4.6 (Drain1), Wire2.2
PYRO2_control: R2.1, U3.6 (IO3), U4.4 (Gate2)
PYRO_POWER: ARM1.1 (A), C1.1, D4.2 (A), LS1.P, Wire1.1, Wire2.1
SPI CS: U3.26 (IO20); also elsewhere on the board
SPI MISO: U3.27 (IO21); also elsewhere on the board
SPI MOSI: U3.28 (IO22); also elsewhere on the board
SPI SCLK: U3.29 (IO23); also elsewhere on the board
UART0 RX: U3.30 (RXD0); also elsewhere on the board
UART0 TX: U3.31 (TXD0); also elsewhere on the board
USB D+: U3.18 (IO13); also elsewhere on the board
USB D-: U3.17 (IO12); also elsewhere on the board

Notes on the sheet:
Pyro Arming system
2.1V drop expected
Boot and Program capabilities
IMU and Barometer
Processor
LED Array and Pyro Warning
Pyro Firing system
GNSS On-board

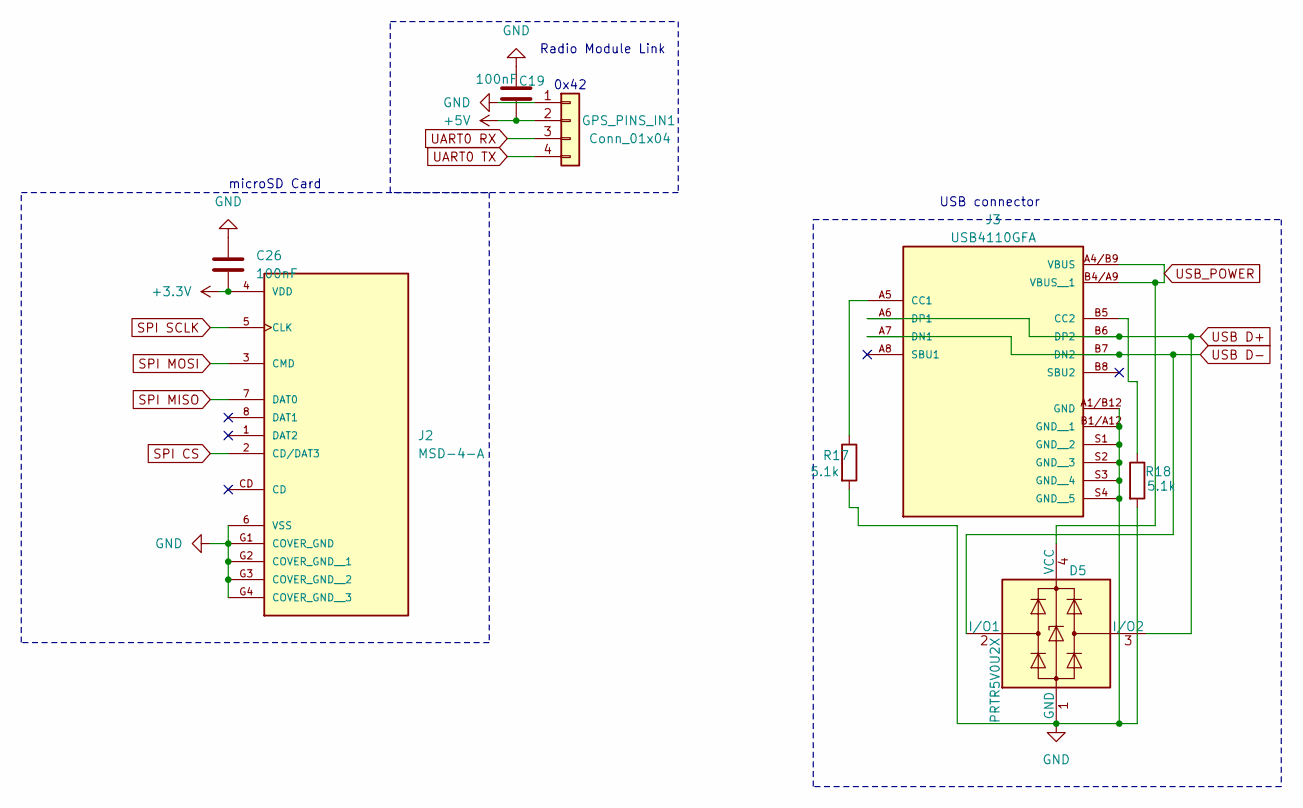
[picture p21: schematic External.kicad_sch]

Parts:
C19, C26: 100nF; C_0603_1608Metric
D5: PRTR5V0U2X; SOT-143
GPS_PINS_IN1: Conn_01x04; PinHeader_1x04_P2.54mm_Vertical
J2: MSD-4-A; CUI_MSD-4-A; PARTREV 1.0
J3: USB4110GFA; GCT_USB4110GFA
R17, R18: 5.1k; R_0603_1608Metric

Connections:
+3.3V: C26.2, J2.4 (VDD); also elsewhere on the board
+5V: C19.2, GPS_PINS_IN1.2; also elsewhere on the board
GND: C19.1, C26.1, D5.1 (GND), GPS_PINS_IN1.1, J2.6 (VSS), J2.G1 (COVER_GND), J2.G2 (COVER_GND__1), J2.G3 (COVER_GND__2), J2.G4 (COVER_GND__3), J3.A1/B12 (GND), J3.B1/A12 (GND__1), J3.S1 (GND__2), J3.S2 (GND__3), J3.S3 (GND__4), J3.S4 (GND__5), R17.2, R18.2; also elsewhere on the board
unnamed: J3.A5 (CC1), R17.1
unnamed: J3.B5 (CC2), R18.1
SPI CS: J2.2 (CD/DAT3); also elsewhere on the board
SPI MISO: J2.7 (DAT0); also elsewhere on the board
SPI MOSI: J2.3 (CMD); also elsewhere on the board
SPI SCLK: J2.5 (CLK); also elsewhere on the board
UART0 RX: GPS_PINS_IN1.3; also elsewhere on the board
UART0 TX: GPS_PINS_IN1.4; also elsewhere on the board
USB D+: D5.3 (I/O2), J3.A6 (DP1), J3.B6 (DP2); also elsewhere on the board
USB D-: D5.2 (I/O1), J3.A7 (DN1), J3.B7 (DN2); also elsewhere on the board
USB_POWER: D5.4 (VCC), J3.A4/B9 (VBUS), J3.B4/A9 (VBUS__1); also elsewhere on the board

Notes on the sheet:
microSD Card
0x42
Radio Module Link
USB connector

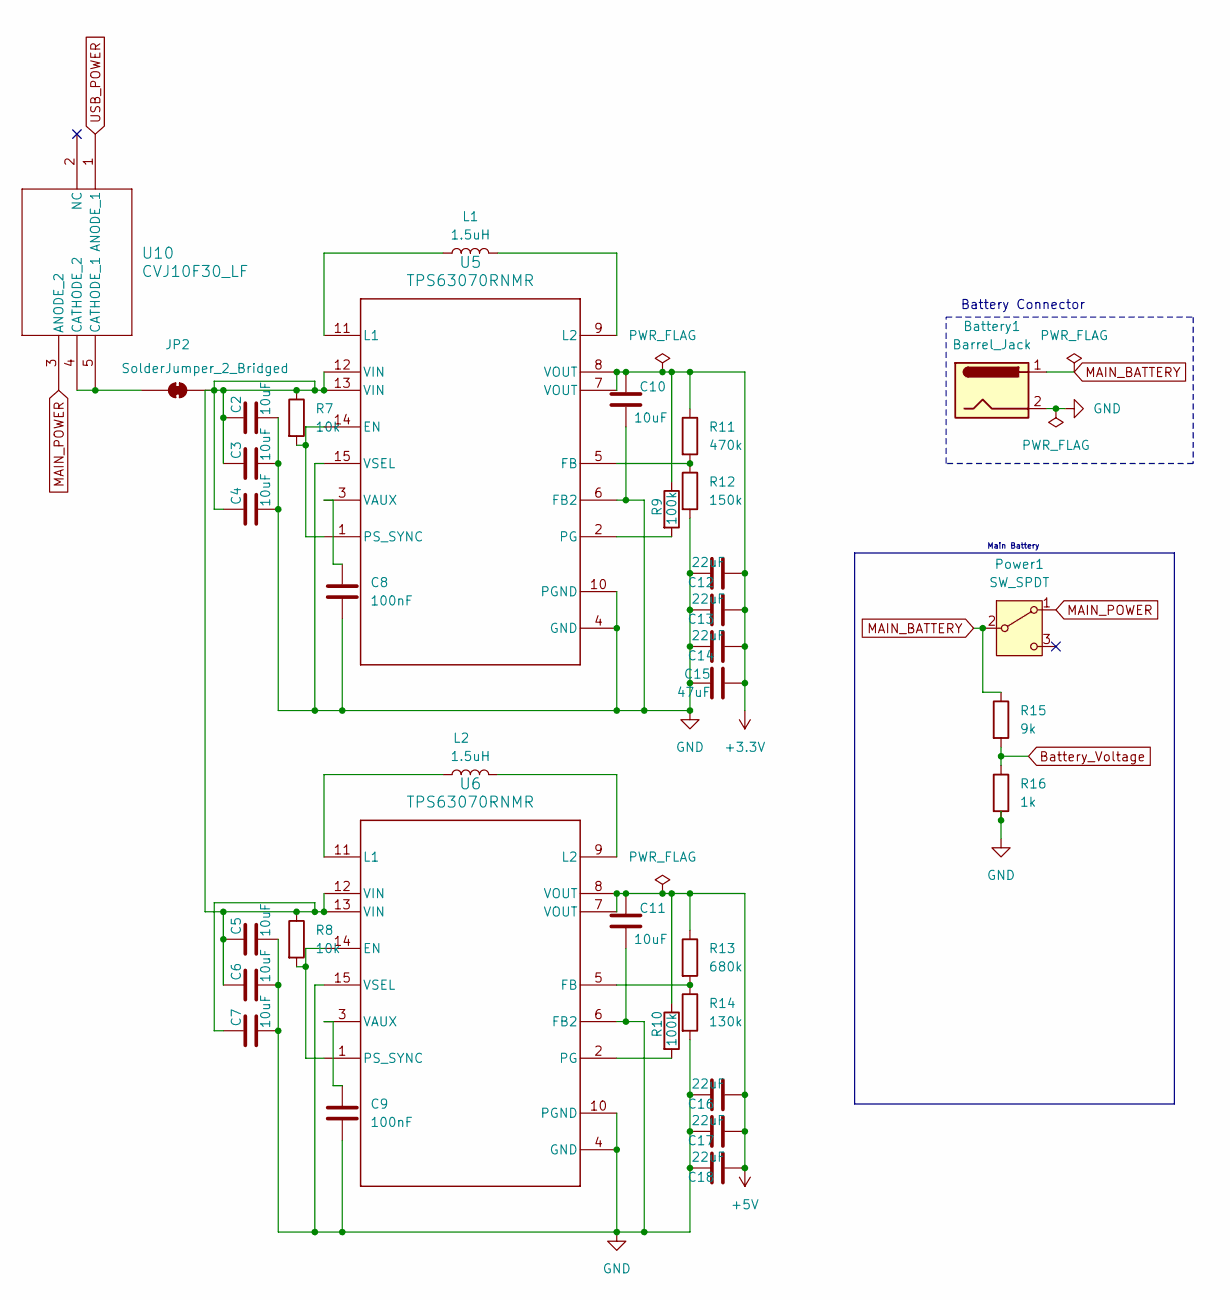
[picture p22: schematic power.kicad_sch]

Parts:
Battery1: Barrel_Jack; PinSocket_1x02_P2.54mm_Vertical
C2, C3, C4, C5, C6, C7, C10, C11: 10uF; C_0603_1608Metric
C8, C9: 100nF; C_0603_1608Metric
C12, C13, C14, C16, C17, C18: 22uF; C_0603_1608Metric
C15: 47uF; C_0603_1608Metric
JP2: SolderJumper_2_Bridged; SolderJumper-2_P1.3mm_Open_Pad1.0x1.5mm
L1, L2: 1.5uH; 1277AS-H-1R0M=P2_MUR-M
Power1: SW_SPDT; PinSocket_1x02_P2.00mm_Vertical
R7, R8: 10k; R_0603_1608Metric
R9, R10: 100k; R_0603_1608Metric
R11: 470k; R_0603_1608Metric
R12: 150k; R_0603_1608Metric
R13: 680k; R_0603_1608Metric
R14: 130k; R_0603_1608Metric
R15: 9k; R_0603_1608Metric
R16: 1k; R_0603_1608Metric
U5, U6: TPS63070RNMR; RNM0015A
U10: CVJ10F30_LF; UFV_TOS-L

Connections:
+3.3V: C10.1, C12.2, C13.2, C14.2, C15.2, R9.1, R11.1, U5.7 (VOUT), U5.8 (VOUT); also elsewhere on the board
+5V: C11.1, C16.2, C17.2, C18.2, R10.1, R13.1, U6.7 (VOUT), U6.8 (VOUT); also elsewhere on the board
Battery_Voltage: R15.2, R16.1; also elsewhere on the board
GND: Battery1.2, C2.1, C3.1, C4.1, C5.1, C6.1, C7.1, C8.2, C9.2, C10.2, C11.2, C12.1, C13.1, C14.1, C15.1, C16.1, C17.1, C18.1, R12.2, R14.2, R16.2, U5.4 (GND), U5.6 (FB2), U5.10 (PGND), U5.15 (VSEL), U6.4 (GND), U6.6 (FB2), U6.10 (PGND), U6.15 (VSEL); also elsewhere on the board
MAIN_BATTERY: Battery1.1, Power1.2 (B), R15.1
MAIN_POWER: Power1.1 (A), U10.3 (ANODE_2); also elsewhere on the board
unnamed: JP2.1 (A), U10.4 (CATHODE_2), U10.5 (CATHODE_1)
unnamed: C2.2, C3.2, C4.2, C5.2, C6.2, C7.2, JP2.2 (B), R7.1, R8.1, U5.12 (VIN), U5.13 (VIN), U6.12 (VIN), U6.13 (VIN)
unnamed: R7.2, U5.1 (PS_SYNC), U5.14 (EN)
unnamed: R11.2, R12.1, U5.5 (FB)
unnamed: L1.1, U5.11 (L1)
unnamed: L1.2, U5.9 (L2)
unnamed: R9.2, U5.2 (PG)
unnamed: C8.1, U5.3 (VAUX)
unnamed: R8.2, U6.1 (PS_SYNC), U6.14 (EN)
unnamed: R13.2, R14.1, U6.5 (FB)
unnamed: L2.1, U6.11 (L1)
unnamed: L2.2, U6.9 (L2)
unnamed: R10.2, U6.2 (PG)
unnamed: C9.1, U6.3 (VAUX)
USB_POWER: U10.1 (ANODE_1); also elsewhere on the board

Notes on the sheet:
Main Battery
Battery Connector

Board: 4 copper layers, 75 parts (1 on the bottom side), 47 nets, no tracks yet.

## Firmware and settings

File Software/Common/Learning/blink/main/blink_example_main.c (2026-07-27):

/* Blink Example

   This example code is in the Public Domain (or CC0 licensed, at your option.)

   Unless required by applicable law or agreed to in writing, this
   software is distributed on an "AS IS" BASIS, WITHOUT WARRANTIES OR
   CONDITIONS OF ANY KIND, either express or implied.
*/
#include <stdio.h>
#include "freertos/FreeRTOS.h"
#include "freertos/task.h"
#include "driver/gpio.h"
#include "esp_log.h"
#include "led_strip.h"
#include "sdkconfig.h"

static const char *TAG = "example";

/* Use project configuration menu (idf.py menuconfig) to choose the GPIO to blink,
   or you can edit the following line and set a number here.
*/
#define BLINK_GPIO CONFIG_BLINK_GPIO

static uint8_t s_led_state = 0;

#ifdef CONFIG_BLINK_LED_STRIP

static led_strip_handle_t led_strip;

static void blink_led(void)
{
    /* If the addressable LED is enabled */
    if (s_led_state) {
        /* Set the LED pixel using RGB from 0 (0%) to 255 (100%) for each color */
        led_strip_set_pixel(led_strip, 0, 16, 16, 16);
        /* Refresh the strip to send data */
        led_strip_refresh(led_strip);
    } else {
        /* Set all LED off to clear all pixels */
        led_strip_clear(led_strip);
    }
}

static void configure_led(void)
{
    ESP_LOGI(TAG, "Example configured to blink addressable LED!");
    /* LED strip initialization with the GPIO and pixels number*/
    led_strip_config_t strip_config = {
        .strip_gpio_num = BLINK_GPIO,
        .max_leds = 1, // at least one LED on board
    };
#if CONFIG_BLINK_LED_STRIP_BACKEND_RMT
    led_strip_rmt_config_t rmt_config = {
        .resolution_hz = 10 * 1000 * 1000, // 10MHz
        .flags.with_dma = false,
    };
    ESP_ERROR_CHECK(led_strip_new_rmt_device(&strip_config, &rmt_config, &led_strip));
#elif CONFIG_BLINK_LED_STRIP_BACKEND_SPI
    led_strip_spi_config_t spi_config = {
        .spi_bus = SPI2_HOST,
        .flags.with_dma = true,
    };
    ESP_ERROR_CHECK(led_strip_new_spi_device(&strip_config, &spi_config, &led_strip));
#else
#error "unsupported LED strip backend"
#endif
    /* Set all LED off to clear all pixels */
    led_strip_clear(led_strip);
}

#elif CONFIG_BLINK_LED_GPIO

static void blink_led(void)
{
    /* Set the GPIO level according to the state (LOW or HIGH)*/
    gpio_set_level(BLINK_GPIO, s_led_state);
}

static void configure_led(void)
{
    ESP_LOGI(TAG, "Example configured to blink GPIO LED!");
    gpio_reset_pin(BLINK_GPIO);
    /* Set the GPIO as a push/pull output */
    gpio_set_direction(BLINK_GPIO, GPIO_MODE_OUTPUT);
}

#else
#error "unsupported LED type"
#endif

void app_main(void)
{

    /* Configure the peripheral according to the LED type */
    configure_led();

    while (1) {
        ESP_LOGI(TAG, "Turning the LED %s!", s_led_state == true ? "ON" : "OFF");
        blink_led();
        /* Toggle the LED state */
        s_led_state = !s_led_state;
        vTaskDelay(CONFIG_BLINK_PERIOD / portTICK_PERIOD_MS);
    }
}

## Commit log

2026-05-31 Push of current state of work
    Moving from local storage of Git Storage
    [.step, .stl, 3-1478978-1.step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]
2026-05-31 Standalone
    Making projects standalone
    [ErisV1.kicad_pcb, ErisV1.kicad_sch]
2026-05-31 New Parts library
    Centralising into 1 parts library
    [3-1478978-1.step, AI-3035-TT-12V-R.step, BMI270_BOS.stl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]
2026-05-31 Symbol changes to use common library in Iris
    [IrisV1.kicad_sch, Pyro_Logic.kicad_sch, Sensors.kicad_sch]
2026-05-31 Iris final update to inbuilt library
    [IrisV1.kicad_pcb]
2026-06-01 Using Symlinks in library table instead of folders
    All KiCAD projects now use library tables to refer to the common UNSW Rocketry Parts folder
    [3-1478978-1.step, BMI323_BOS.step, CONSMA001-SMD-G-T.step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]
2026-06-01 Centralised Library
    Updating to a centralised library structure
    [.step, 1277AS-H-1R0MP2_MUR.step, AI-3035-TT-12V-R.step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]
2026-06-01 Oneiroi Changes
    All 3D models and footprints updated to common library, silkscreening must be re-done.
    [BMI270_BOS.step, External.kicad_sch, IC_DMP3028LSD-13_DIO.step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]
2026-06-01 Silkscreen Oneiroi
    Adds silkscreen to Oneroi
    [OneroiV1.kicad_pcb]
2026-06-03 Small changes
    Swapping final footprints to use relative filepaths for 3D models, silkscreen DRC.
    [OneroiV1.kicad_pcb]
2026-06-08 Changed to 3.5mm Screw terminals
    All screw terminals in IRIS changed to 3.5mm screw terminals per Oliver's request.
    [EBWA-02-A.step, IrisV1.kicad_pcb, IrisV1.kicad_sch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]
2026-06-24 bom generated
